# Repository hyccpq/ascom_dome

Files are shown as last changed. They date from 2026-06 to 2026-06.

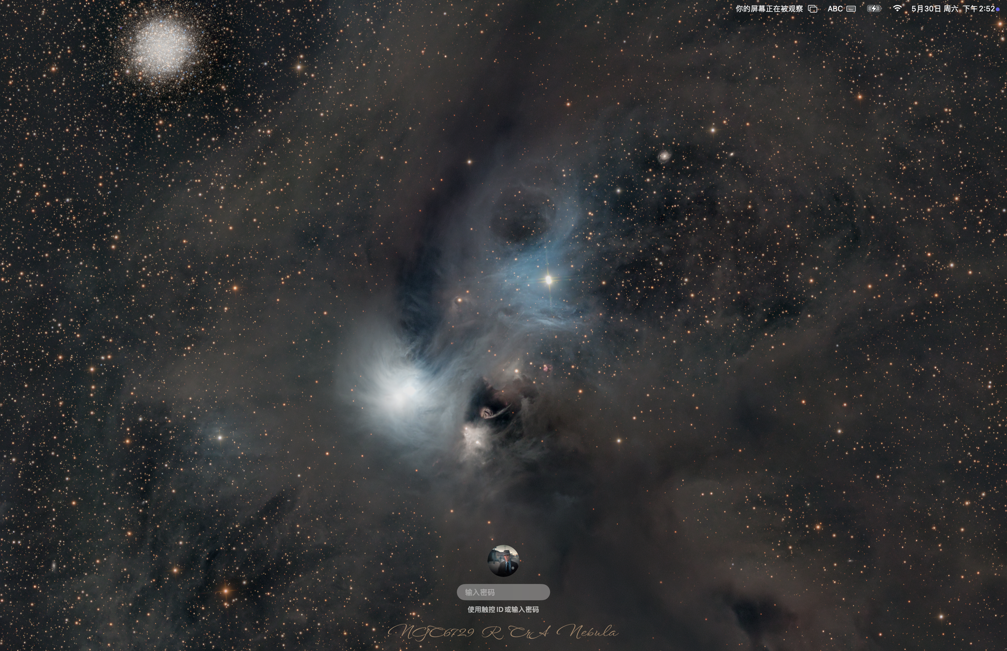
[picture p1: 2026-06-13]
hardware/jlceda/out/pcb3_outer_io_layout_screen.png

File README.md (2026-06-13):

# Ascom Alpaca ESP32 Dome Board

ESP32-S3 firmware for controlling a roll-off-roof / sliding dome top through the ASCOM Alpaca protocol.

This trimmed version keeps only the Dome control path:

- Alpaca Dome discovery and API endpoints
- Web page for Dome state and Open / Close / Halt commands
- Web setup for Dome pins and timeout settings
- WiFi manager connection flow
- OTA firmware and filesystem updates

Switch and CoverCalibrator modules have been removed from the firmware, web UI, SPIFFS defaults, and Alpaca device discovery.

## ESP32-S3 Dome I/O

The current firmware uses fixed GPIO definitions in `src/board_pins.h`:

| Signal | GPIO |
| --- | --- |
| Open command relay trigger | 4 |
| Close command relay trigger | 5 |
| Stop / halt command relay trigger | 6 |
| Open limit input | 7 |
| Close limit input | 8 |
| Reserved rain sensor input | 9 |

The three relay outputs are intended to pulse external isolated trigger inputs for open, close, and stop. The rain sensor header is initialized as an input and reported in diagnostics, but it does not automatically close the dome until the sensor polarity and desired safety behavior are defined.

The web setup page still stores the original dome configuration file for compatibility, but the active control pins are the fixed GPIO constants above.

Detailed hardware notes are in `docs/esp32-s3-dome-board-hardware.md`.

ESP32-S3 dome board wiring draft

## Build

Install Visual Studio Code and the PlatformIO extension, then open this folder as a PlatformIO project.

From the command line:

```sh
pio run
```

To build the SPIFFS image:

```sh
pio run --target buildfs
```

## First Upload

Use PlatformIO:

1. Upload Filesystem Image
2. Upload firmware

On first boot, connect to the WiFi manager access point and configure the board for your observatory WiFi.

## Web Interface

After the board joins WiFi, open the ESP32 IP address in a browser.

- `/` shows Dome status and Open / Close / Halt controls.
- `/setup` shows Dome configuration.
- `/update` is provided by ElegantOTA for firmware and filesystem updates.

## ASCOM Alpaca

The board listens for Alpaca discovery on UDP `32227` and serves Alpaca device requests on port `4567`.

Only one configured device is advertised:

- Device type: `Dome`
- Device number: `0`

Useful endpoints include:

- `GET /management/apiversions`
- `GET /management/v1/description`
- `GET /management/v1/configureddevices`
- `GET /api/v1/dome/0/shutterstatus`
- `PUT /api/v1/dome/0/openshutter`
- `PUT /api/v1/dome/0/closeshutter`
- `PUT /api/v1/dome/0/abortslew`

## Verification

Current smoke check:

```sh
pio run
```

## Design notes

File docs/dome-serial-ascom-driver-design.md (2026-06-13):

# Dome Serial Control and ASCOM Driver Design

This document defines the next development slice for the ESP32 dome controller:

1. Add a local serial control protocol to the firmware.
2. Build a Windows ASCOM Dome driver for ASCOM Platform 6.6 and later.
3. Keep the current Alpaca and browser controls working through the same internal dome command/state model.

## Current Firmware Baseline

The firmware is now dome-only.

Relevant files:

- `src/main.cpp` starts WiFi, Alpaca discovery, Dome routes, browser routes, OTA, and `main_loop()`.
- `src/Dome/dome.h` owns dome GPIO setup, command pulses, input state detection, and the movement state machine.
- `src/Dome/domeVariable.h` defines `Dome`, `ShCmdEnum`, `ShStEnum`, and `ShInEnum`.
- `src/Dome/alpacaDevices.h` exposes Alpaca Dome API methods.
- `src/Dome/webserver.h` exposes browser-facing `/api/dome` and `/api/dome-cmd`.

The serial protocol should not duplicate dome movement logic. It should only translate serial commands into the existing `Dome.ShutterCommand` and report the existing `Dome.ShutterState`.

## Official ASCOM References

Use these official references during implementation:

- ASCOM Platform 6.6 SP2 developer help: `https://ascom-standards.org/Help/Developer/html/N_ASCOM_DriverAccess.htm`
- ASCOM Platform requirements: `https://ascom-standards.org/Help/Developer/html/6cd2ca86-9e45-4a9e-8693-32d338c949a3.htm`
- ASCOM Dome DriverAccess class for Platform 6.6: `https://ascom-standards.org/Help/Developer/html/T_ASCOM_DriverAccess_Dome.htm`
- ASCOM Master Interfaces Dome API reference: `https://ascom-standards.org/library/html/T_ASCOM_DeviceInterface_IDomeV3.htm`
- ASCOM Alpaca API reference: `https://ascom-standards.org/api/`

Interpretation for this project:

- ASCOM Platform 6.6 targets .NET Framework 4.8.
- The 6.6 DriverAccess Dome class documents `IDomeV2` compatibility.
- Newer ASCOM interface documentation includes `IDomeV3`.
- For broad client compatibility, implement the first Windows driver as an ASCOM 6.6-compatible Dome driver, with a small internal adapter layer so an `IDomeV3` facade can be added later without rewriting serial transport.

## Serial Protocol Goals

The serial protocol is for a direct USB connection between Windows and the ESP32.

Goals:

- Human-readable for field debugging in a serial terminal.
- Line-oriented and non-blocking on the ESP32.
- Stable enough for an ASCOM driver.
- Idempotent status reads.
- Simple command acknowledgements.
- No JSON parsing required in the hot loop.

Transport defaults:

- Baud: `115200`
- Data bits: `8`
- Parity: `None`
- Stop bits: `1`
- Line ending: `\n`; accept optional preceding `\r`
- Encoding: ASCII
- Read timeout on driver side: 1000 ms
- Command timeout on driver side: 3000 ms

## Serial Protocol Version

Protocol name: `KDB1`

Every command is one line:

```text
KDB1 <COMMAND> [ARGS...]
```

Every response is one line:

```text
OK <FIELDS...>
ERR <CODE> <MESSAGE>
```

The driver must ignore blank lines. The firmware should trim whitespace and treat command names case-insensitively.

## Serial Commands

### `PING`

Request:

```text
KDB1 PING
```

Response:

```text
OK PONG KDB1
```

Driver use:

- Verify selected COM port.
- Reconnect health check.

### `INFO`

Request:

```text
KDB1 INFO
```

Response:

```text
OK NAME=KalecDome PROTO=KDB1 FW=1.0 DEVICE=DOME
```

Driver use:

- Confirm this is the expected device.
- Display firmware/protocol in setup dialog.

### `STATE`

Request:

```text
KDB1 STATE
```

Response:

```text
OK STATE=OPEN CMD=IDLE INPUT=OPEN MOVING=0 ERROR=0
```

Allowed `STATE` values:

- `OPEN`
- `CLOSED`
- `OPENING`
- `CLOSING`
- `ERROR`

Allowed `CMD` values:

- `IDLE`
- `OPEN`
- `CLOSE`
- `HALT`

Allowed `INPUT` values:

- `NONE`
- `CLOSE`
- `OPEN`
- `BOTH`

Driver mapping:

| Firmware state | ASCOM shutter status |
| --- | --- |
| `OPEN` | `shutterOpen` |
| `CLOSED` | `shutterClosed` |
| `OPENING` | `shutterOpening` |
| `CLOSING` | `shutterClosing` |
| `ERROR` | `shutterError` |

### `OPEN`

Request:

```text
KDB1 OPEN
```

Success response:

```text
OK CMD=OPEN
```

Error responses:

```text
ERR 1035 ALREADY_OPEN_OR_MOVING
ERR 1001 DEVICE_ERROR
```

Firmware behavior:

- If state is already `OPEN`, return `ERR 1035 ALREADY_OPEN_OR_MOVING`.
- If no movement is active, set `Dome.ShutterCommand = CmdOpen`.
- Do not block waiting for the movement to finish.

### `CLOSE`

Request:

```text
KDB1 CLOSE
```

Success response:

```text
OK CMD=CLOSE
```

Error responses:

```text
ERR 1035 ALREADY_CLOSED_OR_MOVING
ERR 1001 DEVICE_ERROR
```

Firmware behavior:

- If state is already `CLOSED`, return `ERR 1035 ALREADY_CLOSED_OR_MOVING`.
- If no movement is active, set `Dome.ShutterCommand = CmdClose`.
- Do not block waiting for the movement to finish.

### `HALT`

Request:

```text
KDB1 HALT
```

Response:

```text
OK CMD=HALT
```

Firmware behavior:

- Set `Dome.ShutterCommand = CmdHalt`.
- Set `Dome.Cycle = 100` to enter the existing halt cycle.

### `CONFIG?`

Request:

```text
KDB1 CONFIG?
```

Response:

```text
OK OPEN_RELAY=4 CLOSE_RELAY=5 HALT_RELAY=6 OPEN_INPUT=7 CLOSE_INPUT=8 RAIN_INPUT=9 TIMEOUT=300
```

Driver use:

- Show read-only hardware summary in the setup dialog.

## Firmware Implementation Plan

Add a new firmware module:

- `src/Dome/serialControl.h`

Current status: implemented.

Expose:

```cpp
void domeSerialSetup();
void domeSerialLoop();
```

Call sites:

- In `setup()`, call `domeSerialSetup()` after `initDomeConfig()`.
- In `main_loop()`, call `domeSerialLoop()` after `domehandlerloop()`.

Implementation notes:

- Reuse the existing `Serial.begin(115200)` from `setup()`.
- Maintain a small input buffer, for example 96 bytes.
- Read from `Serial.available()` without blocking.
- Process a command only after `\n`.
- Reject overlong lines with `ERR 1002 LINE_TOO_LONG`.
- Keep all response generation in one small helper.
- Avoid `delay()` in serial parsing; dome movement code already contains command pulse delays.

Suggested errors:

| Code | Meaning |
| --- | --- |
| `1000` | Unknown command |
| `1001` | Device error |
| `1002` | Line too long |
| `1003` | Bad protocol prefix |
| `1035` | Invalid operation for current state |

Implemented command examples:

```text
> KDB1 PING
< OK PONG KDB1

> KDB1 INFO
< OK NAME=KalecDome PROTO=KDB1 FW=1.0 DEVICE=DOME

> KDB1 STATE
< OK STATE=CLOSED CMD=IDLE INPUT=CLOSE MOVING=0 ERROR=0

> KDB1 OPEN
< OK CMD=OPEN

> KDB1 CLOSE
< OK CMD=CLOSE

> KDB1 HALT
< OK CMD=HALT

> KDB1 CONFIG?
< OK OPEN_RELAY=4 CLOSE_RELAY=5 HALT_RELAY=6 OPEN_INPUT=7 CLOSE_INPUT=8 RAIN_INPUT=9 TIMEOUT=300
```

## ASCOM Driver Architecture

Project type:

- Windows ASCOM Dome driver.
- C#.
- .NET Framework 4.8.
- Built with ASCOM Platform 6.6 developer components.
- COM-registered local driver using ASCOM driver templates where possible.

Driver identity:

- ProgID: `ASCOM.KalecDome.Dome`
- Display name: `Kalec Dome Serial`
- Device type: `Dome`

Internal layers:

| Layer | Responsibility |
| --- | --- |
| `DomeDriver` | ASCOM interface implementation and COM registration surface |
| `DomeController` | Maps ASCOM methods/properties to transport commands |
| `SerialTransport` | Owns `System.IO.Ports.SerialPort`, timeouts, reconnect, command lock |
| `ProtocolParser` | Parses `OK` / `ERR` response lines and typed fields |
| `ProfileSettings` | Stores COM port, baud, trace option, command timeout |
| `SetupDialog` | Lets user select/test COM port |

Threading:

- Serialize all COM port access with a single lock.
- Never allow concurrent serial commands.
- Keep ASCOM properties fast by using `STATE` polling with a short timeout.
- Throw ASCOM exceptions on serial timeout or protocol error.

## ASCOM Dome Method Mapping

| ASCOM member | Driver behavior |
| --- | --- |
| `Connected get` | Return internal connection state |
| `Connected set true` | Open COM port, send `PING`, send `INFO` |
| `Connected set false` | Close COM port |
| `Name` | `Kalec Dome Serial` |
| `Description` | `Serial ASCOM driver for Kalec ESP32 dome controller` |
| `DriverInfo` | Include driver version and protocol version |
| `DriverVersion` | Semantic version, start with `0.1.0` |
| `InterfaceVersion` | `2` for ASCOM Platform 6.6 compatibility |
| `ShutterStatus` | Send `STATE`, map firmware state to ASCOM enum |
| `OpenShutter()` | Send `OPEN` |
| `CloseShutter()` | Send `CLOSE` |
| `AbortSlew()` | Send `HALT` |
| `CanSetShutter` | `true` |
| `Slewing` | `true` for `OPENING` or `CLOSING` |
| `CanFindHome` | `false` |
| `CanPark` | `false` |
| `CanSetAltitude` | `false` |
| `CanSetAzimuth` | `false` |
| `CanSetPark` | `false` |
| `CanSlave` | `false` |
| `CanSyncAzimuth` | `false` |
| Unsupported movement/position methods | Throw ASCOM `MethodNotImplementedException` |
| Unsupported position properties | Throw ASCOM `PropertyNotImplementedException` |

For a later `IDomeV3` facade, keep connection operations inside `DomeController` so async connect/disconnect semantics can wrap the same serial connect/test sequence.

## Driver Setup Dialog

Fields:

- COM port dropdown.
- Baud rate, default `115200`; advanced setting.
- Test connection button.
- Trace logging checkbox.
- Timeout setting, default `3000 ms`.

Test flow:

1. Open selected port.
2. Send `KDB1 PING`.
3. Send `KDB1 INFO`.
4. Show device name, firmware version, and protocol.
5. Save settings only after successful test, unless the user explicitly overrides in the dialog.

## Validation and Test Plan

Firmware:

- `pio run`
- `pio run --target buildfs`
- Serial terminal manual tests:
  - `KDB1 PING`
  - `KDB1 INFO`
  - `KDB1 STATE`
  - `KDB1 OPEN`
  - `KDB1 CLOSE`
  - `KDB1 HALT`

Driver:

- Unit test protocol parser with representative `OK` and `ERR` lines.
- Unit test ASCOM state mapping.
- Manual setup dialog test against ESP32.
- ASCOM Diagnostics device selection.
- ASCOM Conform test for Dome behavior.
- N.I.N.A. connection smoke test.

Hardware safety checks:

- Verify OPEN command pulses only GPIO 4.
- Verify CLOSE command pulses only GPIO 5.
- Verify HALT pulls GPIO 6 high and clears open/close relays.
- Verify state reads map GPIO 7/8 to open/closed/error consistently.
- Verify repeated `OPEN` while moving does not re-trigger a relay pulse.

## Implementation Milestones

1. Firmware serial protocol skeleton:
   - Add `serialControl.h`.
   - Support `PING`, `INFO`, `STATE`.
   - Verify with serial monitor.

2. Firmware command execution:
   - Add `OPEN`, `CLOSE`, `HALT`, `CONFIG?`.
   - Verify relay behavior and no blocking parser issues.

3. Driver scaffold:
   - Create ASCOM Dome driver project.
   - Add profile settings and setup dialog.
   - Implement `SerialTransport`.

4. Driver command mapping:
   - Implement connection, status, open, close, halt.
   - Add parser and mapping tests.

5. Compatibility testing:
   - ASCOM Diagnostics.
   - ASCOM Conform.
   - N.I.N.A. or other ASCOM 6.6+ client.

## Open Design Decisions

- Whether to keep the driver serial-only or add optional Alpaca-over-WiFi fallback later.
- Whether firmware pin configuration should remain stored in `domeconfig.txt` or be fully replaced by fixed GPIO constants.
- Whether the ASCOM driver should expose a polling interval setting or always poll on demand.
- Whether the driver installer should be WiX/MSI or a simpler developer registration script for early testing.

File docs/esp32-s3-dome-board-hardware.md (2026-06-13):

# ESP32-S3 平移顶控制板硬件设计建议

本文档记录当前控制板的建议硬件方案。目标是用 ESP32-S3 控制天文台平移顶，通过 ASCOM Alpaca / Web / 串口命令触发开顶、关顶、停止，并为雨感、急停和 RS485 扩展预留接口。

## 设计结论

第一版建议采用：

- 三路继电器干接点作为主控制输出：开、关、停。
- 两路限位输入作为核心状态反馈：开到位、关到位。
- 一路雨感输入预留，先只做状态采集，不直接自动关顶。
- 一路急停输入预留，优先级高于所有软件命令。
- RS485 作为扩展接口预留，不作为第一版主控制依赖。

这样做的好处是兼容性高、调试简单、现场故障容易定位，同时保留后续接 Modbus RTU、PLC 或智能电机控制器的空间。

## 接线框图

下面是第一版建议的直观接线结构。ESP32-S3 控制板负责网络、状态机和继电器触发；外部电机控制器仍然负责真正的大功率电机动作。

```mermaid
flowchart LR
    subgraph Board["ESP32-S3 平移顶控制板"]
        ESP["ESP32-S3\nAlpaca / Web / Serial"]
        RelayOpen["开继电器\nGPIO 4"]
        RelayClose["关继电器\nGPIO 5"]
        RelayStop["停继电器\nGPIO 6"]
        Inputs["输入保护 / 滤波\nGPIO 7 / 8 / 9"]
        RS485["RS485 预留\nUART + DE/RE"]
        Power["电源转换\nVIN -> 5V -> 3V3"]
    end

    subgraph OutputTB["继电器输出接线柱"]
        OpenTB["OPEN_COM / OPEN_NO"]
        CloseTB["CLOSE_COM / CLOSE_NO"]
        StopTB["STOP_COM / STOP_NO"]
    end

    subgraph MotorCtrl["外部电机/门机控制器"]
        OpenIn["开按钮输入"]
        CloseIn["关按钮输入"]
        StopIn["停按钮输入"]
        Motor["平移顶电机"]
    end

    subgraph SensorTB["状态输入接线柱"]
        OpenLimit["开到位限位"]
        CloseLimit["关到位限位"]
        Rain["雨感传感器"]
        Estop["急停输入"]
    end

    subgraph LocalTB["本地按钮接线柱"]
        ManualOpen["本地开"]
        ManualClose["本地关"]
        ManualStop["本地停"]
    end

    subgraph CommTB["通信/电源接线柱"]
        AB["RS485 A / B / GND"]
        Vin["VIN+ / VIN- / PE"]
    end

    ESP --> RelayOpen --> OpenTB --> OpenIn
    ESP --> RelayClose --> CloseTB --> CloseIn
    ESP --> RelayStop --> StopTB --> StopIn
    OpenIn --> Motor
    CloseIn --> Motor
    StopIn --> Motor

    OpenLimit --> Inputs --> ESP
    CloseLimit --> Inputs
    Rain --> Inputs
    Estop --> Inputs
    ManualOpen --> Inputs
    ManualClose --> Inputs
    ManualStop --> Inputs

    ESP <--> RS485 <--> AB
    Vin --> Power --> ESP
```

核心理解：

- 左边继电器输出只是模拟按钮，不直接驱动电机。
- 下方限位、雨感、急停、本地按钮都走低压输入端子。
- RS485 只是预留扩展，不影响第一版三继电器控制。
- 电源输入、继电器触点、低压输入尽量分区放置。

## 固件引脚定义

当前固件固定使用 `src/board_pins.h` 中的板级引脚定义：

| 功能 | GPIO | 方向 | 说明 |
| --- | --- | --- | --- |
| Open relay trigger | GPIO 4 | 输出 | 开顶继电器触发 |
| Close relay trigger | GPIO 5 | 输出 | 关顶继电器触发 |
| Halt relay trigger | GPIO 6 | 输出 | 停止继电器触发 |
| Open limit | GPIO 7 | 输入 | 开到位限位 |
| Close limit | GPIO 8 | 输入 | 关到位限位 |
| Rain sensor | GPIO 9 | 输入 | 雨感预留输入 |

继电器输出在上电初始化时会被拉低，避免启动瞬间误触发。

## 控制输出

### 推荐形式

三路输出建议使用继电器干接点：

- `OPEN_RELAY`: 模拟外部控制器的“开”按钮。
- `CLOSE_RELAY`: 模拟外部控制器的“关”按钮。
- `STOP_RELAY`: 模拟外部控制器的“停”按钮。

干接点不要把本板 GND 或电源直接带到外部电机控制器。这样可以兼容更多门机、卷帘门控制板、PLC 输入和自制控制箱。

### 继电器驱动建议

每路继电器建议包含：

- ESP32-S3 GPIO 驱动三极管或 MOSFET。
- 线圈反灌保护二极管。
- 继电器动作 LED。
- 触点侧使用接线端子引出 `COM` / `NO`，必要时可增加 `NC`。
- 继电器线圈供电与 MCU 电源做好去耦。

如果空间允许，可以选用光耦继电器或信号继电器。普通机械继电器最直观，现场维护也方便。

### 触发时间

当前固件的开/关/停继电器脉冲约为 1 秒。后续可以把脉冲时间做成配置项：

| 输出 | 建议可配置范围 |
| --- | --- |
| 开继电器 | 200 ms - 2000 ms |
| 关继电器 | 200 ms - 2000 ms |
| 停继电器 | 200 ms - 2000 ms |

有些控制器只需要短按，有些控制器需要稍长按压，保留可配置会更稳。

## 状态输入

### 限位输入

至少需要两路限位输入：

- `OPEN_LIMIT`: 屋顶完全打开。
- `CLOSE_LIMIT`: 屋顶完全关闭。

建议输入侧做以下保护：

- 明确上拉或下拉，不让输入悬空。
- 串联限流电阻。
- RC 滤波，减少长线干扰。
- TVS 或 ESD 保护。
- 必要时使用光耦隔离。

平移顶电机附近干扰较多，限位线又可能比较长，输入保护比“能读到电平”更重要。

### 状态判定

固件当前按两路限位组合判断状态：

| 开限位 | 关限位 | 状态 |
| --- | --- | --- |
| 有效 | 无效 | 已打开 |
| 无效 | 有效 | 已关闭 |
| 有效 | 有效 | 运动中或停止在中间 |
| 无效 | 无效 | 异常状态 |

实际硬件接线时要确认限位开关是常开还是常闭，并让固件读取到的电平符合这个状态表。后续如果改用常闭安全回路，建议同步调整固件状态表和文档。

## 雨感接口

建议预留一路雨感输入端子：

- `RAIN_SENSOR`
- `GND`
- `3V3` 或 `5V`，按传感器模块选择

雨感模块常见输出有两类：

- 数字量输出：干湿阈值由模块电位器决定。
- 模拟量输出：湿度程度由 ADC 读取。

第一版建议先接数字量输入，因为逻辑简单、可靠性高。固件目前只初始化雨感输入并在诊断中报告引脚，不自动关顶。等确认传感器输出极性后，再决定：

- 雨感触发时禁止开顶。
- 雨感触发且屋顶未关闭时自动关顶。
- 雨感触发后需要人工确认才能重新开顶。

雨感属于安全相关输入，不建议第一版在没有现场验证的情况下直接自动动作。

## 急停和安全联锁

建议预留急停输入，优先级高于 Web、Alpaca、串口和自动逻辑。

推荐策略：

- 急停触发时立即断开开/关继电器输出。
- 急停触发时允许或强制触发停继电器，取决于外部控制器逻辑。
- 急停解除后不自动恢复动作，需要新的人工命令。

更保守的硬件方案是增加继电器输出总使能，使急停能在硬件层面切断所有运动命令。软件停机很好，但硬件急停更可靠。

## RS485 预留

RS485 不建议作为第一版主控制输出，但强烈建议预留。

### 适合 RS485 的场景

- 外部电机控制器支持 Modbus RTU。
- 后续要接 PLC。
- 需要读取更多状态，例如电机故障码、电流、速度、门机状态。
- 设备距离较长，现场干扰较重。

### 不适合作为第一版主控制的原因

- 必须知道并维护对方协议。
- 不同控制器协议差异大。
- 调试复杂度高于开关量。
- 更换电机控制器时固件可能也要改。

### 硬件预留建议

预留一组 UART 给 RS485 收发器，例如 MAX3485 / SP3485：

| 信号 | 说明 |
| --- | --- |
| TXD | ESP32-S3 UART TX |
| RXD | ESP32-S3 UART RX |
| DE/RE | 方向控制 GPIO |
| A | RS485 A |
| B | RS485 B |
| GND | 通信参考地 |

板上建议增加：

- 120R 终端电阻，使用跳帽或拨码开关启用。
- 偏置电阻位置，按总线实际情况决定是否焊接。

## PCB 布局约束

当前 JLCEDA 生产候选页面为 `ascom_dome` / `Board3_1` / `PCB3`，按低成本 2 层板方向整理：

- 板框约为 `3600 mil x 3450 mil`，控制在常见低价打样尺寸内。
- 四角预留 M3 安装孔，孔径约 `3.4 mm`，非金属化孔。
- 上边放限位/雨感/RS485 预留端子，底边放 `5V IN` 和 USB-C，右边放三路继电器干接点端子，方便现场压线。
- 三路继电器触点输出使用较粗走线，低压 GPIO/传感器信号使用细线。
- RS485 收发器、120R 终端电阻作为预留/可不焊方案，第一版不依赖 RS485。
- ESP32-S3-WROOM 天线区域在文档层标出；正式下单前必须以 live `PCB3` 重新确认无铜、无走线、无过孔、无器件。

当前 JLCEDA 外设布局预览见 [pcb3_outer_io_current_simplified.svg.png](/Users/kalec/Desktop/Ascom-Alpacha-ESP32-Switch-Borad-Dome-Board/hardware/jlceda/out/pcb3_outer_io_current_simplified.svg.png)。

JLCEDA `PCB3` 是当前目标生产候选。此前 live `PCB3` 已完成嘉立创/LCSC 器件、M3 孔位避让、开路检查和铜间距检查；但当前 `R1/R2` 边距修正仍停留在脚本侧，JLCEDA 客户端/bridge 断开后还没有写入并读回确认。正式下单前仍需重新连接、应用当前脚本、同步原理图网表并重新跑 UI DRC。JLCEDA 客户端不可用时，仓库里还保留一份本地 KiCad 机械/布局基线，便于继续检查板框、M3 孔位、端子位置和成本策略：

- KiCad PCB: [esp32_s3_dome_controller.kicad_pcb](/Users/kalec/Desktop/Ascom-Alpacha-ESP32-Switch-Borad-Dome-Board/hardware/kicad/esp32_s3_dome_controller.kicad_pcb)
- 当前交付索引: [esp32-s3-dome-board-delivery.md](/Users/kalec/Desktop/Ascom-Alpacha-ESP32-Switch-Borad-Dome-Board/docs/esp32-s3-dome-board-delivery.md)
- KiCad 预览图: [kicad-esp32-s3-dome-controller-preview.svg](/Users/kalec/Desktop/Ascom-Alpacha-ESP32-Switch-Borad-Dome-Board/docs/kicad-esp32-s3-dome-controller-preview.svg)
- KiCad DRC 报告: [drc.rpt](/Users/kalec/Desktop/Ascom-Alpacha-ESP32-Switch-Borad-Dome-Board/hardware/kicad/out/drc.rpt)
- KiCad Gerber/Drill 草包: [fab](/Users/kalec/Desktop/Ascom-Alpacha-ESP32-Switch-Borad-Dome-Board/hardware/kicad/out/fab)
- KiCad Gerber/Drill 草包 ZIP: [esp32_s3_dome_controller_fab_preview.zip](/Users/kalec/Desktop/Ascom-Alpacha-ESP32-Switch-Borad-Dome-Board/hardware/kicad/out/esp32_s3_dome_controller_fab_preview.zip)
- V1 BOM 成本草表: [esp32-s3-dome-board-bom.csv](/Users/kalec/Desktop/Ascom-Alpacha-ESP32-Switch-Borad-Dome-Board/docs/esp32-s3-dome-board-bom.csv)
- 标准化器件分配表: [esp32-s3-dome-board-standard-parts.md](/Users/kalec/Desktop/Ascom-Alpacha-ESP32-Switch-Borad-Dome-Board/docs/esp32-s3-dome-board-standard-parts.md)
- 标准化器件 CSV: [esp32-s3-dome-board-standard-parts.csv](/Users/kalec/Desktop/Ascom-Alpacha-ESP32-Switch-Borad-Dome-Board/docs/esp32-s3-dome-board-standard-parts.csv)
- 嘉立创/LCSC 物料候选 BOM: [esp32-s3-dome-board-jlc-bom.csv](/Users/kalec/Desktop/Ascom-Alpacha-ESP32-Switch-Borad-Dome-Board/docs/esp32-s3-dome-board-jlc-bom.csv)
- 嘉立创/LCSC 物料核对记录: [esp32-s3-dome-board-jlc-source-check.md](/Users/kalec/Desktop/Ascom-Alpacha-ESP32-Switch-Borad-Dome-Board/docs/esp32-s3-dome-board-jlc-source-check.md)
- JLCEDA 收尾清单: [esp32-s3-dome-board-jlceda-finish-checklist.md](/Users/kalec/Desktop/Ascom-Alpacha-ESP32-Switch-Borad-Dome-Board/docs/esp32-s3-dome-board-jlceda-finish-checklist.md)
- 封装替换映射表: [esp32-s3-dome-board-footprint-map.csv](/Users/kalec/Desktop/Ascom-Alpacha-ESP32-Switch-Borad-Dome-Board/docs/esp32-s3-dome-board-footprint-map.csv)
- 投板/装配注意事项: [esp32-s3-dome-board-fab-notes.md](/Users/kalec/Desktop/Ascom-Alpacha-ESP32-Switch-Borad-Dome-Board/docs/esp32-s3-dome-board-fab-notes.md)
- 坐标文件: [esp32_s3_dome_controller_pos.csv](/Users/kalec/Desktop/Ascom-Alpacha-ESP32-Switch-Borad-Dome-Board/hardware/kicad/out/esp32_s3_dome_controller_pos.csv)

这份 KiCad 文件是离线备份基线，不替代 JLCEDA `PCB3` 正式投板文件。此前 JLCEDA `PCB3` 已记录以下候选状态，bridge 恢复后必须用当前脚本重新复验：

- 使用嘉立创/LCSC 器件源；此前 `scripts/jlceda_verify_lcsc_parts.mjs` 确认 30 个器件的 `supplierId` 均匹配预期。
- 标准化器件已经固定在 `docs/esp32-s3-dome-board-standard-parts.md` 和 `.csv`，用于约束 FIT/DNP、替代料和下单前检查。
- `J5/R8/U2` 作为 RS485 预留默认不进 BOM，其余 V1 必需器件进 BOM。
- USB-C 已靠底边并朝外，`J1 5V IN` 同在底边；J2/J3/J4 继电器输出端子靠右边。
- J6/J7/J8/J5 位于上边，分别用于开限位、关限位、雨感和 RS485 预留。
- 非母线类信号走线已改为 45 度倒角；`5V/GND/3V3/RS485` 这类公共母线保持直连，避免倒角切断分支汇合点。
- `J1/J6/J7/J8` 已从四角 M3 孔附近让开；此前 `scripts/jlceda_verify_mounting_clearance.mjs` 检查四个孔周围器件、走线、过孔命中均为 `0`。
- 此前 `scripts/jlceda_find_open_nets_layered.mjs` 检查 `openNetCount: 0`。
- 此前 `scripts/jlceda_check_clearance.mjs` 检查线/焊盘、线/线、线/过孔、过孔/过孔冲突均为 `0`。
- 此前 JLCEDA `pcb_Drc.check(true, false, true)` 检查无 clearance、slot、connection 等物理布线错误；`P2.Schematic3` 已按 `PCB3` 修正继电器 pinout、RS485 A/B、USB/EN 和外壳 GND，直接 Ref.Pin 比对显示 `103` 个 P2 有网引脚与 `103` 个 PCB3 有网焊盘完全一致。当前只剩 1 条 JLCEDA UI generic `Netlist Error / Import Changes` 同步项；正式下单前需要先应用当前 `R1/R2` 脚本修正，再清掉该 UI 项并重新跑 DRC。

当前 KiCad 备份布局已完成以下内容：

- 板框约 `91.44 mm x 87.63 mm`，控制在 `100 mm x 100 mm` 以内。
- 四角 M3 非金属化安装孔已预留。
- 电源输入、限位/雨感输入、RS485 预留和三路继电器干接点端子均靠板边布置。
- ESP32-S3-WROOM 天线禁布区已在 PCB `Dwgs.User` 层标注；正式换官方封装时，天线端必须朝板边，禁布区内不能有铜皮、走线、过孔或器件。
- 三路继电器触点侧已使用较粗走线，输入侧和控制侧使用细走线。
- 已补入输入端子、雨感、GND、5V、3V3、三路继电器驱动、RS485 A/B 和 USB-C 调试口的布线。
- 已新增 `J9 USB-C DEVICE`，作为 ESP32-S3 原生 USB 下载/调试口；`VBUS` 接 5V，`D-`/`D+` 接 ESP32-S3 USB 引脚，`CC1`/`CC2` 各接 5.1k 下拉。
- `J1 5V IN` 已保留为外部 5V 接线柱输入，并在板上补充 `GND +5V IN` 丝印，避免现场接线只看编号。
- DRC 未发现短路、交叉、clearance、hole-clearance 或 solder-mask-bridge 硬错误。
- DRC 当前未连接项为 `0`，严格错误检查为 `0`。
- KiCad 备份完整 DRC 仍有 `34` 条 `lib_footprint_mismatch` 警告，来源是生成的 `Codex:*` 占位封装；若单独用 KiCad 备份投板，必须先替换成嘉立创/立创 EDA 可采购封装。此前 JLCEDA `PCB3` 已用真实 LCSC 封装完成候选构建，但当前仍需 bridge 恢复后复验。

### 成本优化建议

- 第一版保持 2 层板，不做 4 层板。
- 板子尺寸继续压在 `100 mm x 100 mm` 内。
- RS485 相关器件可标注为 DNP，现场确认需要后再焊；其中 `R8 120R` 终端电阻建议第一版默认 DNP。
- 端子尽量统一间距和型号，减少 BOM 种类。
- 继电器只引出 `COM/NO`，如果现场确认不需要 `NC`，不额外增加三位端子。
- M3 孔使用普通非金属化安装孔，不做沉金、半孔等特殊工艺。
- 贴装电阻优先用嘉立创 Basic 0603：`100R C22775`、`10k C25804`、`120R C22787`、`5.1k C23186`。

### KiCad 备份 PCB 状态

已完成：

- 板框恢复到 PCB 内部的 Board Outline 层。
- 四角 M3 安装孔已放入 PCB。
- 三路继电器干接点输出已布到底层端子：`OPEN_COM/NO`、`CLOSE_COM/NO`、`STOP_COM/NO`。
- 继电器线圈低端到 MOSFET/续流二极管的本地连接已整理。
- 5V 和 3V3 已完成一部分电源主干。
- R4/R5/R6 已移到 ESP32-S3 附近并旋转，使输入信号焊盘朝向 MCU，降低端子区拥挤度。
- `OPEN_LIMIT_GPIO7`、`CLOSE_LIMIT_GPIO8`、`RAIN_GPIO9` 已从端子经底层走线接到 ESP32-S3 输入和上拉电阻。
- R1/R2/R3 已重新摆放到 MOSFET gate 附近，三路 `OPEN_GATE`、`CLOSE_GATE`、`STOP_GATE` 已接到 MOSFET 门极。
- `OPEN_GPIO4`、`CLOSE_GPIO5`、`STOP_GPIO6` 已从 ESP32-S3 接到 R1/R2/R3，三路继电器控制信号已收线。
- R1 已下移并同步调整 `OPEN_GPIO4` 末端走线，为 `OPEN_COIL_LOW` 继续优化预留间距。
- 三路继电器 5V 线圈供电主干已串接，D2 5V 支路已补齐。
- `J9 USB-C DEVICE` 已放在板边，采用低成本原生 USB 方案，不增加 USB-UART 芯片。
- U3 到 C1 的 3V3 去耦支路已绕开 U3 中间脚完成。
- RS485 的 `RE` / `DE` 已在 U2 旁短接，便于后续用一个 GPIO 控制方向。
- RS485 A/B 已从 U2 收发器接到 J5 端子；R8 终端电阻仍建议按 DNP/跳帽方案保留。
- U3 稳压器 GND 和 Q1 继电器驱动源极已补过孔接入底层 GND 回路。

KiCad 备份基线如果继续单独投板，还需要：

- RS485 RO/DI 与 MCU UART 的预留走线仍建议在原理图层面确认；当前 PCB 侧 A/B 端子和 R8 DNP 位已保留。
- 如果为了进一步降 BOM 成本决定删除 `R8 120R`，必须原理图和 PCB 同步删除或同步改为 DNP；不要只在 PCB 端删除，否则会产生 netlist mismatch。
- GND 建议最终用覆铜处理，并在 ESP32-S3 模块 GND、Q2/Q3 源极、U3、J6/J7/J5/J9 GND 处补回流过孔；如果 API 覆铜不可用，就保持当前分区地线加过孔的策略。
- USB-C 最终投板前应换成实际采购的 Type-C 母座封装，并按所选连接器核对外壳脚、定位孔和板边开口。
- ESP32-S3 模组最终投板前必须用官方 footprint 复核天线 keepout；如果真实封装和当前占位 U1 不一致，优先调整 U1 位置/方向，让天线禁布区伸向板边空旷区域。

当前 KiCad 离线版 DRC 没有短路、交叉、clearance、hole-clearance、solder-mask-bridge 或未连接错误。丝印重叠/压铜警告已清理；剩余主要是自定义占位 footprint 与库副本不一致的警告，因此这版可作为继续导入/复刻到 JLCEDA 的电气布局基线，但正式投板前仍要替换为真实封装。
- TVS 管保护 A/B 线。
- 接线端子标清 A/B/GND。

## 电源和保护

建议供电结构：

- 外部输入：推荐 12 V 或 24 V，按现场供电选择。
- 板载降压到 5 V，给继电器和部分外设。
- 再降压到 3.3 V，给 ESP32-S3。

保护建议：

- 输入保险丝或自恢复保险。
- 电源反接保护。
- 输入 TVS。
- 继电器线圈独立去耦。
- ESP32-S3 3.3 V 电源留足瞬态余量。
- 外部长线接口增加 ESD/浪涌保护。

## 调试和维护

强烈建议板上放这些指示灯：

| 指示灯 | 作用 |
| --- | --- |
| POWER | 主电源正常 |
| 3V3 | MCU 电源正常 |
| WIFI/STATUS | 系统运行状态 |
| OPEN_RELAY | 开继电器动作 |
| CLOSE_RELAY | 关继电器动作 |
| HALT_RELAY | 停继电器动作 |
| OPEN_LIMIT | 开到位输入 |
| CLOSE_LIMIT | 关到位输入 |
| RAIN | 雨感输入 |
| ESTOP | 急停输入 |

另外建议预留：

- USB-C 或 USB-UART 下载调试口。
- BOOT / RESET 按键。
- UART TX/RX 测试点。
- 3V3 / 5V / GND 测试点。
- RS485 A/B 测试点。

现场调试时，输入输出 LED 会极大减少排查时间。

## 推荐端子规划

板子上尽量把外部连接都做成接线柱，方便现场接线、排查和后期替换设备。建议端子按功能分组，避免强弱电混在一起；每组端子旁边直接丝印功能名，不要只写 GPIO 编号。

推荐优先使用 3.5 mm 或 5.08 mm 间距插拔式接线端子。低压信号可以用 3.5 mm，继电器触点和外部控制线建议用 5.08 mm，现场拧线会舒服很多。

### 建议接线柱编号

第一版建议直接按下面编号画原理图和 PCB 丝印。编号不是强制，但这样后续对文档、原理图和接线说明时不容易乱。

| 编号 | 建议端子 | 间距 | 端子定义 | 备注 |
| --- | --- | --- | --- | --- |
| J1 | 电源输入 | 5.08 mm 3P | `VIN+`, `VIN-`, `PE/SHIELD` | 推荐 12 V 或 24 V 输入，按电源方案定 |
| J2 | 开继电器输出 | 5.08 mm 2P/3P | `OPEN_COM`, `OPEN_NO`, 可选 `OPEN_NC` | 干接点模拟开按钮 |
| J3 | 关继电器输出 | 5.08 mm 2P/3P | `CLOSE_COM`, `CLOSE_NO`, 可选 `CLOSE_NC` | 干接点模拟关按钮 |
| J4 | 停继电器输出 | 5.08 mm 2P/3P | `STOP_COM`, `STOP_NO`, 可选 `STOP_NC` | 干接点模拟停按钮 |
| J5 | 限位/安全输入 | 3.5 mm 6P | `OPEN_LIMIT`, `CLOSE_LIMIT`, `RAIN_SENSOR`, `EMERGENCY_STOP`, `GND`, `SENSOR_VCC` | `SENSOR_VCC` 建议跳帽选 3V3/5V |
| J6 | 本地按钮输入 | 3.5 mm 4P | `MANUAL_OPEN`, `MANUAL_CLOSE`, `MANUAL_STOP`, `GND` | 固件可后续接入 |
| J7 | RS485 | 3.5 mm 3P/4P | `A`, `B`, `GND`, 可选 `5V_OUT` | 预留 Modbus/PLC 扩展 |
| J8 | 下载/调试 | 2.54 mm 排针或 USB-C | `USB_D+`, `USB_D-`, `5V`, `GND` 或 UART | 结合 ESP32-S3 下载方式决定 |

当前 KiCad 离线版为了先压低成本和面积，端子编号略有简化：`J1` 是 2P `GND/+5V IN`，`J6/J7/J8` 分别是开限位、关限位和雨感输入，`J9` 是 USB-C 下载/调试口。正式同步到 JLCEDA 时，建议按最终原理图重新统一编号和丝印。

如果板子空间允许，继电器输出建议全部做 3P：`COM/NO/NC`。如果空间紧张，继电器输出至少做 2P：`COM/NO`。

### 继电器输出端子

三路继电器输出是最核心接口，建议每路独立接线柱：

```text
OPEN_COM
OPEN_NO
CLOSE_COM
CLOSE_NO
STOP_COM
STOP_NO
```

如空间允许，更推荐每路 `COM / NO / NC` 三端子，兼容常开和常闭外部回路：

```text
OPEN_COM
OPEN_NO
OPEN_NC
CLOSE_COM
CLOSE_NO
CLOSE_NC
STOP_COM
STOP_NO
STOP_NC
```

如果板子空间紧张，第一版至少保留 `COM / NO`。多数外部控制器模拟按钮只需要常开干接点。

### 状态输入端子

状态输入建议集中放一组接线柱，并给传感器供电预留公共端：

```text
OPEN_LIMIT
CLOSE_LIMIT
RAIN_SENSOR
EMERGENCY_STOP
GND
3V3/5V_SENSOR
```

如果使用三线传感器或不同电压雨感模块，可以把传感器电源单独做跳帽选择：

```text
SENSOR_VCC = 3V3 / 5V selectable
```

### 本地按钮输入

本地按钮输入建议预留接线柱，即使第一版固件暂时不用，PCB 上留出来后面会很省事：

```text
MANUAL_OPEN
MANUAL_CLOSE
MANUAL_STOP
GND
```

本地按钮输入可以先预留硬件，固件后续再接入。这样网络不可用时仍有本地操作空间。

### RS485 端子

RS485 建议独立一组 3 pin 接线柱：

```text
RS485_A
RS485_B
GND
```

端子旁边建议预留终端电阻跳帽：

```text
120R_TERM_ENABLE
```

如果 PCB 空间允许，也可以把 RS485 的电源一起引出，方便接外部隔离模块或小型从设备：

```text
RS485_A
RS485_B
GND
5V_OUT
```

### 电源输入端子

电源输入也建议用接线柱，不要只依赖 USB：

```text
VIN+
VIN-
PE / SHIELD
```

`PE / SHIELD` 可按现场情况接机箱地、屏蔽层或悬空，至少 PCB 上预留焊盘或端子位置。

### 推荐端子总表

第一版如果想“能接的都留好”，建议至少预留：

| 分组 | 建议端子 |
| --- | --- |
| 电源 | `VIN+`, `VIN-`, `PE/SHIELD` |
| 开继电器 | `OPEN_COM`, `OPEN_NO`, 可选 `OPEN_NC` |
| 关继电器 | `CLOSE_COM`, `CLOSE_NO`, 可选 `CLOSE_NC` |
| 停继电器 | `STOP_COM`, `STOP_NO`, 可选 `STOP_NC` |
| 限位/传感器 | `OPEN_LIMIT`, `CLOSE_LIMIT`, `RAIN_SENSOR`, `EMERGENCY_STOP`, `GND`, `SENSOR_VCC` |
| 本地按钮 | `MANUAL_OPEN`, `MANUAL_CLOSE`, `MANUAL_STOP`, `GND` |
| RS485 | `A`, `B`, `GND`, 可选 `5V_OUT` |

布局上建议把“继电器触点端子”和“低压输入端子”分开放，丝印方向统一朝外，端子边缘留足螺丝刀操作空间。

## 固件后续建议

后续固件可以继续增强：

- 开/关/停脉冲时间配置。
- 雨感极性配置。
- 雨感触发策略配置：仅报警、禁止开顶、自动关顶。
- 急停输入逻辑。
- 输入消抖时间配置。
- 错误状态在 Web 页面明确显示。
- 串口 `STATE` 增加雨感和急停状态。
- RS485 Modbus RTU 扩展。

## JLCEDA 原理图 V1 边界

当前 JLCEDA 原理图建议先按 V1 框架推进，不要急着一次画成最终量产版。

V1 原理图应至少包含：

- ESP32-S3-WROOM-1 主控。
- 三路继电器：`OPEN`, `CLOSE`, `STOP`。
- 三路继电器驱动：MOSFET/三极管、栅极/基极电阻、下拉电阻、反灌二极管、动作 LED。
- 输入接口：开限位、关限位、雨感、急停、本地开/关/停按钮。
- 输入保护：串阻、上拉/下拉、RC 滤波、TVS/ESD 预留位。
- RS485 收发器、A/B/GND 端子、120R 终端电阻跳帽、TVS 预留位。
- 电源：VIN 输入保护、5V 电源、3V3 LDO/降压、必要去耦电容。
- 下载调试：USB-C 或 USB-UART、BOOT、RESET、TX/RX 测试点。

V1 暂不建议直接定死的内容：

- 雨感是否自动关顶。
- RS485 上层协议。
- 限位输入常开/常闭最终极性。
- 外部门机是否需要 `NO` 还是 `NC` 触点。

这些内容更适合等现场控制器、限位开关、雨感模块确定后再锁定。

## 画板前审查清单

原理图转 PCB 前，至少做一轮人工检查：

- ESP32-S3 启动相关引脚没有被外部电路错误拉高/拉低。
- 三路继电器上电默认不吸合。
- 继电器触点侧和 MCU 低压侧保持清楚隔离，不把板上电源误送到外部门机按钮输入。
- 所有外部长线输入都有明确默认电平，不悬空。
- 雨感和限位输入能通过跳帽或焊接位适配常开/常闭、低有效/高有效。
- RS485 A/B 命名在端子、丝印和原理图中一致。
- 120R 终端电阻默认可断开，不强制一直并在总线上。
- 电源输入有反接、过流、浪涌或至少预留保护位。
- 端子边缘留足螺丝刀空间，强弱电区域物理分开。
- 所有接线柱丝印使用功能名，不只写 `J1-1` 这种编号。

## 第一版验收清单

硬件打样后建议至少验证：

- 上电后三路继电器不误动作。
- Web / Alpaca / 串口发开命令时，只有开继电器动作。
- 发关命令时，只有关继电器动作。
- 发停命令时，开/关继电器关闭，停继电器动作。
- 开到位和关到位输入显示正确。
- 两个限位输入异常组合能进入错误状态。
- 雨感输入电平能被稳定读取。
- 急停输入能阻止运动命令。
- WiFi 连接和 OTA 页面可用。
- SPIFFS 默认配置能正常加载。
- RS485 预留脚位没有与现有功能冲突。

## 当前推荐

当前项目最稳的路线是：

```text
主控制：三路继电器干接点
核心反馈：开到位 / 关到位
安全输入：雨感 / 急停
扩展通信：RS485 预留
调试辅助：每路输入输出 LED + USB 串口
```

第一版先把开关量链路做可靠，后续再把 RS485 和更复杂的自动策略加上去。

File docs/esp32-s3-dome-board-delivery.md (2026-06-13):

# ESP32-S3 Dome Board Delivery Index

This is the current PCB delivery snapshot for the ESP32-S3 dome controller V1. As of 2026-05-31, treat it as a production candidate only: the live JLCEDA bridge is not connected, so final JLCEDA UI DRC/export is still pending.

## Current V1 Scope

- Controller: ESP32-S3 module.
- Outputs: three relay dry-contact triggers for `OPEN`, `CLOSE`, and `STOP`.
- Inputs: open limit, close limit, and rain sensor terminals.
- Expansion: RS485 A/B reserved, DNP by default.
- Debug/power: USB-C native ESP32-S3 USB plus external `5V IN` terminal.
- Mounting: four corner M3 NPTH holes.
- Cost target: 2-layer board below `100 mm x 100 mm`, low-cost HASL-compatible first article.
- RF layout: ESP32-S3-WROOM antenna keepout must be left empty: no copper, no traces, no vias, and no components.

The current KiCad V1 board uses external `5V IN` to reduce first-article BOM cost. A future 12/24V input plus buck converter can be added after field power requirements are confirmed.

## Authoritative Artifacts

| Purpose | File |
| --- | --- |
| KiCad offline preview/import baseline | `hardware/kicad/esp32_s3_dome_controller.kicad_pcb` |
| Project file | `hardware/kicad/esp32_s3_dome_controller.kicad_pro` |
| Preview image | `docs/kicad-esp32-s3-dome-controller-preview.svg` |
| JLCEDA outer-IO preview image | `hardware/jlceda/out/pcb3_outer_io_current_simplified.svg.png` |
| Hardware design notes | `docs/esp32-s3-dome-board-hardware.md` |
| Routing/finalization checklist | `docs/pcb2-routing-punchlist.md` |
| Costed V1 BOM draft | `docs/esp32-s3-dome-board-bom.csv` |
| Standard parts assignment | `docs/esp32-s3-dome-board-standard-parts.md` |
| Standard parts machine table | `docs/esp32-s3-dome-board-standard-parts.csv` |
| JLC/LCSC BOM candidate | `docs/esp32-s3-dome-board-jlc-bom.csv` |
| JLC/LCSC source check | `docs/esp32-s3-dome-board-jlc-source-check.md` |
| JLCEDA finish checklist | `docs/esp32-s3-dome-board-jlceda-finish-checklist.md` |
| JLCEDA import and binding notes | `docs/esp32-s3-dome-board-jlceda-import-and-bind.md` |
| Real footprint replacement map | `docs/esp32-s3-dome-board-footprint-map.csv` |
| JLCEDA parts manifest | `docs/esp32-s3-dome-board-jlceda-parts-manifest.csv` |
| Fabrication notes | `docs/esp32-s3-dome-board-fab-notes.md` |
| Strict DRC report | `hardware/kicad/out/drc-errors.rpt` |
| Full DRC report | `hardware/kicad/out/drc.rpt` |
| Gerber/drill preview ZIP | `hardware/kicad/out/esp32_s3_dome_controller_fab_preview.zip` |
| KiCad import ZIP for JLCEDA | `hardware/kicad/out/esp32_s3_dome_controller_kicad_import.zip` |
| Position file | `hardware/kicad/out/esp32_s3_dome_controller_pos.csv` |
| JLCPCB FIT BOM draft | `hardware/kicad/out/jlcpcb_assembly_bom_fit.csv` |
| JLCPCB DNP BOM draft | `hardware/kicad/out/jlcpcb_assembly_bom_dnp.csv` |
| JLCPCB CPL draft | `hardware/kicad/out/jlcpcb_cpl_fit.csv` |
| JLCEDA direct PCB build script | `scripts/jlceda_populate_pcb.mjs` |
| JLCEDA official-pad routing script | `scripts/jlceda_route_official_pads.mjs` |
| JLCEDA final outer-IO routing script | `scripts/jlceda_layout_outer_io_route.mjs` |
| Local static candidate verifier | `scripts/verify_local_board_candidate.mjs` |
| JLCEDA PCB verification script | `scripts/jlceda_verify_pcb3.mjs` |
| JLCEDA LCSC binding verification script | `scripts/jlceda_verify_lcsc_parts.mjs` |
| JLCEDA mounting-hole clearance verification script | `scripts/jlceda_verify_mounting_clearance.mjs` |
| JLCEDA live production gate runner | `scripts/jlceda_apply_and_verify_pcb3_production.mjs` |

## Completion Evidence

| Requirement | Evidence | Status |
| --- | --- | --- |
| Four corner M3 mounting holes | `MH1`..`MH4`, NPTH pads with `3.41 mm` drill in the PCB file | Done |
| Board kept low-cost size | Edge cuts are `91.44 mm x 87.63 mm` | Done |
| 2-layer layout | PCB uses `F.Cu` and `B.Cu` signal layers | Done |
| Three relay outputs | `K1/K2/K3` routed to `J2/J3/J4` dry-contact terminals | Done |
| Rain sensor reserved | `J8 RAIN` terminal routed to `RAIN_GPIO9` | Done |
| 5V input present | `J1 5V IN` terminal and `GND +5V IN` silkscreen | Done |
| USB present | `J9 USB-C DEVICE`, CC pulldowns `R9/R10`, D+/D- routed to ESP32-S3 USB pads | Done |
| Routed without strict KiCad DRC errors | Fresh `hardware/kicad/out/drc-errors-fresh.rpt` reports `0` violations and `0` unconnected pads | Done for KiCad backup |
| Cost optimization documented | JLC BOM marks RS485 and terminator DNP, keeps 2-pin relay terminals, uses native USB, module ESP32-S3, Basic 0603 resistors, and 2-layer board | Done |
| ESP32 antenna keepout called out | `PCB3` includes a document-layer antenna warning rectangle. Current local verifier also warns that the KiCad backup has stale parts/copper in the KiCad antenna rectangle, so KiCad is not an order source. | Needs live PCB3 recheck |
| JLCEDA bridge checked | 2026-05-31 status: `http://127.0.0.1:9151/v1/status` returns `connected:false`; 9050-9059 WS discovery received no extension hello; `jlc-assistant` UI times out and `open -a /Applications/jlc-assistant.app` fails with `-1712`. Log evidence shows `autoSaveInTime: 保存成功` at `2026-05-31 04:21:32`, followed by login-expired `401` at `04:22:19`. `TERM` and `KILL` did not release the stuck `UE` process. | Blocked for live JLCEDA verification |
| JLCEDA floating schematic page cleaned | JLCEDA page `4f59e624d870fc29` was rebuilt via `jlceda-mcp-bridge` with 30 JLC/LCSC components and 7 aligned section notes; snapshot confirmed the component count | Done as schematic/BOM anchor |
| JLCEDA linked schematic source cleaned | Linked board `Board3_1` uses `Schematic3`; page `P1` / UUID `018b50bd6ee3ee7a` is deprecated and has been cleared to the drawing sheet only | Done |
| JLCEDA linked schematic populated | Formal source page is `P2.Schematic3` / UUID `227f009d50838569`; readback confirmed the 30 PCB designators `K1/K2/K3`, `J1`..`J9`, `U1/U2/U3`, `Q1`..`Q3`, `D1`..`D3`, `R1`..`R6`, and `R8/R9/R10`, with no extra part designators | Done as linked schematic |
| JLCEDA linked PCB created | `PCB3` UUID `5664b0722a0b08df` is linked under `Board3_1` | Created, not imported |
| JLCEDA PCB import from schematic | Earlier `pcb_Document.importChanges("720bbc0db4383d2e")` and default `pcb_Document.importChanges()` returned `false`; after P2 cleanup, `pcb_Document.importChanges("227f009d50838569")` returned `true`, but JLCEDA still reports one `Netlist Error / Import Changes` item | Physical PCB is verified; UI netlist sync remains an order gate |
| JLCEDA direct PCB build | `scripts/jlceda_populate_pcb.mjs` populated `PCB3` with 30 real JLC/LCSC components, board outline, four M3 holes, 199 line primitives, and 26 vias; JLCEDA UI shows the board on `PCB3` | Superseded by official-pad routing |
| JLCEDA final outer-IO routing script | `scripts/jlceda_layout_outer_io_route.mjs` keeps USB-C on the bottom edge, field terminals on board edges, and now places `R1/R2` at `x=2130mil` to give more margin from the relay body while staying outside the antenna warning area. | Script updated; rerun on PCB3 when bridge reconnects |
| JLCEDA live production gate runner | `scripts/jlceda_apply_and_verify_pcb3_production.mjs` runs the local static check, applies the current PCB3 layout/routing script, runs all PCB3 readback checks, then runs P2 import plus JLCEDA PCB DRC. With the current disconnected bridge it fails before any live write. | Ready; blocked on bridge |
| JLCEDA PCB readback | Previous readback from `scripts/jlceda_verify_pcb3.mjs` reported 30 components, no missing/extra expected designators, 298 line primitives, 12 strings, and no listed support parts inside the antenna warning area. | Must rerun after applying current script |
| JLCEDA mounting clearance | `scripts/jlceda_verify_mounting_clearance.mjs` reported `componentHitCount: 0`, `lineHitCount: 0`, and `viaHitCount: 0` around `MH1`..`MH4` | Done |
| JLCEDA connectivity | `scripts/jlceda_find_open_nets_layered.mjs` reported `openNetCount: 0` | Done |
| JLCEDA local clearance scan | `scripts/jlceda_check_clearance.mjs` reported `lineHitCount: 0`, `lineLineHitCount: 0`, `lineViaHitCount: 0`, and `viaHitCount: 0` | Done |
| JLCEDA LCSC bindings | `scripts/jlceda_verify_lcsc_parts.mjs` reported all 30 components match expected LCSC supplier IDs; `J5/R8/U2` are excluded from BOM by default | Done |
| JLCEDA P2 relay/PCB net alignment | P2 was corrected for `K1/K2/K3` relay pinout, `J5` RS485 A/B, `U1` EN/USB D+/D-, `U3.2`, and `J9` shell GND; direct Ref.Pin readback confirmed `103` P2 pins with nets match the `103` PCB3 pads with nets, with mismatch/schematic-only/PCB-only counts all `0` | Done |
| Standard parts assigned | `docs/esp32-s3-dome-board-standard-parts.md` and `.csv` fix the V1 FIT/DNP policy, LCSC numbers, package choices, substitution gates, and order gates | Done |
| JLCEDA PCB DRC via bridge | `pcb_Drc.check(true, false, true)` still reports one generic `Netlist Error / Import Changes` item after import retries, while direct P2-vs-PCB Ref.Pin comparison and `sys_Tool.netlistComparison` show no concrete net differences | Physical PCB and source nets match; clear stale UI netlist item before order export |
| Local static candidate check | `node scripts/verify_local_board_candidate.mjs` confirms P2/PCB3 UUIDs, no active P1 use, edge connector placement, M3 hole coordinates, revised R1/R2 script placement, R1/R2 relay-body margins, and key KiCad relay/MOSFET/flyback/USB/5V/limit/rain pad nets. It warns that the KiCad backup antenna area is stale. | Passes with KiCad-stale warnings |

## Production Gate

The board is not cleared for ordering until the live JLCEDA checks below pass. `PCB3` remains the intended production candidate, but the current R1/R2 script adjustment has not been applied or re-read from the live JLCEDA canvas in this session.

- Re-check live stock/class for the LCSC numbers in `docs/esp32-s3-dome-board-standard-parts.md` and `docs/esp32-s3-dome-board-jlc-bom.csv` before ordering.
- For the MCP-created JLCEDA working set, continue from `Board3_1` / `Schematic3` page `P2` / `PCB3`; keep `P1` cleared and do not use it as a source page.
- Place `U1` with the ESP32-S3-WROOM-1 antenna facing a board edge and keep the marked antenna keepout empty: no copper pour, no tracks, no vias, no components, and no metal mounting hardware.
- Confirm the selected USB-C receptacle footprint against the part ordered.
- Confirm relay footprint pinout against the exact relay ordered.
- Re-run JLCEDA UI DRC after synchronizing/importing the schematic netlist, and keep `全部 (0)` before ordering.
- Re-run `scripts/jlceda_apply_and_verify_pcb3_production.mjs`; it wraps the current layout script, all PCB3 readback checks, P2 import, and JLCEDA PCB DRC gate in the required order.
- Export Gerber, drill, position, and BOM directly from JLCEDA `PCB3` for the real order package.

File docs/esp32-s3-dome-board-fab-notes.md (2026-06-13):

# ESP32-S3 Dome Board Fabrication Notes

## Board Target

- Board size: `91.44 mm x 87.63 mm`.
- Layer count: 2 layers.
- Thickness: `1.6 mm`.
- Copper: `1 oz` is enough for the relay coil and low-voltage signal version.
- Finish: HASL is acceptable for the low-cost first article; ENIG is not required.
- Mounting: four corner M3 NPTH holes, drill about `3.4 mm`.
- ESP32 antenna: keep the module antenna area empty on all copper layers; no traces, vias, copper pour, metal mounting hardware, or components under/in front of the antenna.

## Do Not Order Before These Checks

- Use the JLCEDA `PCB3` production candidate, not the KiCad preview, for the official order package.
- If the KiCad baseline is used for a fresh import, replace every `Codex:*` placeholder footprint with the real JLCEDA/LCSC footprint before ordering.
- When replacing `U1`, use the official ESP32-S3-WROOM-1 keepout and orient the antenna toward a board edge.
- Confirm the selected USB-C connector shell pads, locator holes, and board-edge direction.
- Confirm the selected relay pinout against `K1/K2/K3`; Songle SRD-style relays have common variants.
- Confirm terminal block pitch and screw direction before ordering the PCB.
- Re-run DRC after footprint replacement and keep strict errors at `0`.

## Low-Cost Assembly Choices

- Keep RS485 parts DNP in V1 unless the field wiring really needs it.
- Keep relay outputs as 2-pin `COM/NO` terminals unless `NC` is confirmed necessary.
- Use ESP32-S3 module instead of bare ESP32-S3 chip to avoid RF layout and extra passives.
- Use native ESP32-S3 USB through USB-C; do not add a USB-UART chip.
- Use one resistor package family. For JLC assembly, prefer the Basic 0603 parts listed in `docs/esp32-s3-dome-board-jlc-bom.csv`; switch to 0805 only if hand rework is more important than assembly cost.
- Keep external power as `5V IN` for V1; adding 12/24V buck input is a later cost/function tradeoff.

## Exported Files

- PCB preview: `docs/kicad-esp32-s3-dome-controller-preview.svg`
- DRC strict-error report: `hardware/kicad/out/drc-errors.rpt`
- Full DRC report: `hardware/kicad/out/drc.rpt`
- Gerber/drill preview ZIP: `hardware/kicad/out/esp32_s3_dome_controller_fab_preview.zip`
- Position CSV: `hardware/kicad/out/esp32_s3_dome_controller_pos.csv`
- JLC/LCSC BOM candidate: `docs/esp32-s3-dome-board-jlc-bom.csv`
- JLCPCB FIT BOM draft: `hardware/kicad/out/jlcpcb_assembly_bom_fit.csv`
- JLCPCB DNP list: `hardware/kicad/out/jlcpcb_assembly_bom_dnp.csv`
- JLCPCB CPL draft: `hardware/kicad/out/jlcpcb_cpl_fit.csv`
- JLCEDA finish checklist: `docs/esp32-s3-dome-board-jlceda-finish-checklist.md`

The KiCad Gerber/drill ZIP is a preview package for checking layers, holes, outline, and routing. The intended order source is JLCEDA `PCB3`, not the KiCad preview. Earlier live `PCB3` checks showed LCSC parts, edge-facing USB-C, outer-edge terminals, clean M3 mounting-hole clearances, and no physical PCB DRC clearance/connection errors; however, the current `R1/R2` margin adjustment has not been applied/read back because the JLCEDA bridge is disconnected. Before ordering, reconnect the bridge, rerun the current routing script, clear the remaining generic JLCEDA UI `Netlist Error / Import Changes` item, and re-run JLCEDA DRC/export from `PCB3`.

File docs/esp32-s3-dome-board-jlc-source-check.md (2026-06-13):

# JLC/LCSC Part Source Check

Checked against JLCPCB part-detail pages and JLCEDA library readback. Stock and Basic/Extended class can change, so re-check in JLCEDA before ordering.

| Function | LCSC | MPN / Keyword | JLCPCB page |
| --- | --- | --- | --- |
| ESP32-S3 module | C2913201 | ESP32-S3-WROOM-1-N8R8 | JLCEDA library search |
| 3.3 V LDO | C6186 | AMS1117-3.3 | https://jlcpcb.com/partdetail/AMS1117-33-C6186 |
| RS485 transceiver | C8963 | SP3485EN-L/TR | https://jlcpcb.com/partdetail/Sipex_SP3485EN-L-TR/C8963 |
| Relay | C35449 | SRD-05VDC-SL-C | https://jlcpcb.com/partdetail/SRDSongleRelay-SRD05VDCSLC/C35449 |
| N-MOSFET | C20917 | AO3400A | https://jlcpcb.com/partdetail/ChangjiangMicroelectronics-AO3400A/C20917 |
| Flyback diode | C81598 | 1N4148W | https://jlcpcb.com/partdetail/DiodesIncorporated-1N4148W7F/C81598 |
| 100R resistor | C22775 | 0603 100R | https://jlcpcb.com/partdetail/UNI_ROYAL-UniroyalElec0603WAF1000T5E/C22775 |
| 10k resistor | C25804 | 0603 10k | https://jlcpcb.com/partdetail/UNI_ROYAL-UniroyalElec0603WAF1002T5E/C25804 |
| 120R resistor | C22787 | 0603 120R | https://jlcpcb.com/partdetail/UNI_ROYAL-UniroyalElec0603WAF1200T5E/C22787 |
| 5.1k resistor | C23186 | 0603 5.1k | https://jlcpcb.com/partdetail/UNI_ROYAL-UniroyalElec0603WAF5101T5E/C23186 |
| 5.08 mm terminal | C8465 | WJ500V-5.08-2P | JLCEDA library search |
| 3.81 mm terminal | C9900005589 | KF128-3.81-2P | JLCEDA library search |
| USB-C receptacle | C165948 | HRO TYPE-C-31-M-12 | https://jlcpcb.com/partdetail/HRO-TYPEC31M12/C165948 |

## Notes

- KiCad remains a preview/import baseline and still contains local `Codex:*` footprints. The current JLCEDA production candidate is `ascom_dome` / `PCB3`.
- Earlier live readback with `scripts/jlceda_verify_lcsc_parts.mjs` confirmed all 30 `PCB3` components had `supplier: LCSC` plus the expected `supplierId`; `U2`, `R8`, and `J5` are intentionally `addIntoBom: false`.
- `jlceda-mcp-bridge` was connected earlier with JLCEDA Pro `3.2.135`, but the current 2026-05-31 bridge status is disconnected and must be recovered before order export; see `docs/esp32-s3-dome-board-jlceda-import-and-bind.md`.
- Before ordering, re-check live stock/class in JLCEDA/JLCPCB and verify USB-C shell pads, relay pinout, terminal direction, and ESP32 antenna keepout one last time.

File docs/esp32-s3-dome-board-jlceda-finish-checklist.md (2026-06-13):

# JLCEDA Finish Checklist

Use this checklist to review the current JLCEDA `PCB3` production candidate with JLC/LCSC parts. As of 2026-05-31, this checklist is not complete because the local JLCEDA bridge is disconnected.

## Import / Rebuild

1. Open or recreate the board in JLCEDA Pro.
2. Continue from project `ascom_dome` / board `Board3_1` / PCB `PCB3`.
3. Use `docs/esp32-s3-dome-board-standard-parts.md` and `docs/esp32-s3-dome-board-standard-parts.csv` as the standard FIT/DNP and substitution authority.
4. Use `docs/esp32-s3-dome-board-jlc-bom.csv` as the current grouped LCSC BOM candidate.
5. Use `docs/esp32-s3-dome-board-jlceda-parts-manifest.csv` for confirmed device, symbol, and footprint UUIDs found through `jlceda-mcp-bridge`.
6. Use `docs/esp32-s3-dome-board-jlceda-import-and-bind.md` for import notes and JLCEDA bridge evidence.
7. Keep the KiCad board geometry as the reference:
   - Board size: `91.44 mm x 87.63 mm`.
   - Four M3 NPTH holes: `3.41 mm` drill around the four corners.
   - Relay terminals on the right edge.
   - Input terminals on the top edge.
   - `5V IN` and USB-C near the bottom edge.

## Current MCP Working Set

- Continue from JLCEDA project `ascom_dome`.
- Preferred linked working set: `Board3_1`.
- Schematic source: `Schematic3`, page `P2`, UUID `227f009d50838569`.
- Deprecated schematic page: `P1`, UUID `018b50bd6ee3ee7a`, kept as drawing sheet only with no parts, wires, or extra text.
- PCB target: `PCB3`, UUID `5664b0722a0b08df`.
- The linked schematic has the real JLC/LCSC devices placed. Earlier linked-schematic import calls returned `false`; after the P2 cleanup, `pcb_Document.importChanges("227f009d50838569")` returned `true`, but JLCEDA still keeps one `Netlist Error / Import Changes` DRC item.
- `scripts/jlceda_populate_pcb.mjs` manually rebuilt `PCB3` from the KiCad geometry using real JLC/LCSC device components.
- `scripts/jlceda_layout_outer_io_route.mjs` is the current routing script: USB-C faces the bottom edge, screw terminals are near board edges, and `R1/R2` are now set to `x=2130mil` so they sit between the ESP32 antenna warning area and the relay body instead of under the relay body. Rerun this script on `PCB3` after the bridge reconnects.
- `scripts/jlceda_apply_and_verify_pcb3_production.mjs` is the live production gate runner. After the bridge reconnects, run it to apply the current PCB3 script, rerun all readback checks, import from P2, and execute JLCEDA PCB DRC before export.
- `P2.Schematic3` readback evidence: 30 formal part designators, no missing/extra expected PCB refs, USB-C `J9`, and CC pulldowns `R9/R10` present.
- Previous `scripts/jlceda_verify_pcb3.mjs` readback evidence: 30 components, no missing/extra expected designators, 298 line primitives, 12 strings, and no listed support parts inside the broad antenna warning area. This must be rerun after applying the current R1/R2 script adjustment.
- `scripts/jlceda_verify_mounting_clearance.mjs` readback evidence: the four M3 holes `MH1`..`MH4` have no component, copper line, or via hits inside the configured mounting clearance radii.
- `scripts/jlceda_find_open_nets_layered.mjs` readback evidence: `openNetCount: 0`.
- `scripts/jlceda_check_clearance.mjs` readback evidence: line/pad, line/line, line/via, and via/via hit counts are all `0`.
- `scripts/jlceda_verify_lcsc_parts.mjs` readback evidence: all 30 PCB components use `supplier: LCSC` with the expected `supplierId`; `U2`, `R8`, and `J5` are excluded from BOM by default.
- `docs/esp32-s3-dome-board-standard-parts.md` and `.csv` evidence: V1 standard parts are assigned, RS485 remains default DNP, and substitutions are constrained by footprint/pinout gates.
- Direct JLCEDA PCB DRC evidence before the current script-only `R1/R2` margin adjustment: `pcb_Drc.check(true, false, true)` reported only one `Netlist Error / Import Changes` item and no clearance, slot, connection, or open-copper physical errors. Rerun this after the bridge reconnects and the current routing script is applied.
- Schematic DRC evidence: `jlc.schematic.drc({ strict:false, userInterface:false })` returned `ok:true` after the P1/P2 cleanup.
- P2 net alignment evidence: P2 was corrected for `K1/K2/K3` relay pinout, `J5` RS485 A/B, `U1` EN/USB D+/D-, `U3.2`, and `J9` shell GND; direct Ref.Pin readback confirmed `103` P2 pins with nets match the `103` PCB3 pads with nets, with mismatch/schematic-only/PCB-only counts all `0`.
- Remaining order-gate item: JLCEDA PCB DRC still reports a generic `Netlist Error / Import Changes` after import retries even though direct Ref.Pin net comparison is clean; clear this UI netlist item and re-run `检查DRC` before generating order files.
- Current live-bridge gate: on 2026-05-31, `http://127.0.0.1:9151/v1/status` reports `connected:false`, 9050-9059 discovery receives no extension `hello`, the `jlc-assistant` app UI times out, and `open -a /Applications/jlc-assistant.app` fails with `-1712`. JLCEDA logs show `autoSaveInTime: 保存成功` at `2026-05-31 04:21:32`, followed by login-expired `401` at `04:22:19`; `TERM` and `KILL` did not release the stuck `UE` process. Do not export/order until this is recovered and all PCB3 scripts/DRC are rerun.

## Critical Layout Gates

- ESP32-S3-WROOM-1 antenna side faces a board edge.
- ESP32 antenna keepout has no copper, no tracks, no vias, no components, and no metal mounting hardware.
- Treat the KiCad `Dwgs.User` antenna rectangle as a hard placement warning. The official EasyEDA ESP32-S3-WROOM-1 footprint may shift the exact antenna end slightly, so re-center the no-copper/no-part zone on the real module antenna before final DRC.
- Input pullups and relay driver support parts `Q1/Q2/R1/R2/R4/R5/R6` are intended to stay out of the broad antenna warning area in `PCB3`; the current local script keeps `R1/R2` pulled toward the MOSFET side, but live `PCB3` readback is still required.
- The KiCad backup is stale for antenna-area verification: `node scripts/verify_local_board_candidate.mjs` reports KiCad backup parts/copper in the KiCad antenna rectangle. Use KiCad only as a mechanical/import baseline, not as an order source.
- USB-C connector shell/locator holes match `C165948`.
- Relay pinout matches `C35449` before routing coil and contact pads.
- Terminal screw direction faces outward for field wiring.
- Relay dry-contact outputs remain isolated from ESP32 GND and 5V.
- RS485 parts `U2`, `R8`, and `J5` remain DNP unless the first build needs RS485.

## Cost Gates

- Keep the board 2-layer.
- Use HASL unless there is a clear reason to pay for ENIG.
- Use Basic 0603 resistors where listed:
  - `C22775` 100R
  - `C25804` 10k
  - `C22787` 120R DNP
  - `C23186` 5.1k
- Do not add a USB-UART chip; ESP32-S3 native USB is already routed.
- Do not expand relay terminals to 3P unless `NC` is required in the field.
- Keep `U2`, `R8`, and `J5` DNP unless the first build intentionally includes RS485.

## Files for JLCPCB Assembly Upload

- JLCEDA production candidate: project `ascom_dome` / `Board3_1` / `PCB3`.
- Current final routing script: `scripts/jlceda_layout_outer_io_route.mjs`.
- Live production gate runner: `scripts/jlceda_apply_and_verify_pcb3_production.mjs`.
- Local static candidate verifier: `scripts/verify_local_board_candidate.mjs`.
- Standard parts assignment: `docs/esp32-s3-dome-board-standard-parts.md` and `docs/esp32-s3-dome-board-standard-parts.csv`.
- Confirmed JLCEDA parts manifest: `docs/esp32-s3-dome-board-jlceda-parts-manifest.csv`.
- KiCad preview Gerber/drill ZIP: `hardware/kicad/out/esp32_s3_dome_controller_fab_preview.zip`.
- KiCad import ZIP for JLCEDA: `hardware/kicad/out/esp32_s3_dome_controller_kicad_import.zip`.
- KiCad FIT/DNP/CPL drafts remain useful cross-checks, but the order package should be regenerated from JLCEDA `PCB3`.

These upload files are generated from the KiCad baseline. For ordering, regenerate the official JLCEDA Gerber/BOM/CPL from `PCB3` only after the live bridge reconnects, the current routing script is applied, and JLCEDA DRC reports zero remaining items.

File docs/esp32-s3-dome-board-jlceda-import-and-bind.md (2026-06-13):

# JLCEDA Import and Binding Notes

Use this note when moving the KiCad baseline into JLCEDA Pro for the final production version. The KiCad files are an offline preview/import baseline; the order source must be JLCEDA `PCB3` after live DRC passes.

## MCP Bridge Status

The local `jlceda-mcp-bridge` was tested again on 2026-05-30 and again on 2026-05-31:

- Bridge URL: `http://127.0.0.1:9151`
- JLCEDA extension app: `jlceda-mcp-bridge`
- Bridge version: `0.0.17`
- JLCEDA Pro version reported by the bridge: `3.2.135`
- 2026-05-30 bridge status: connected during earlier verification
- 2026-05-31 bridge status: HTTP bridge is listening, but `connected:false`; 9050-9059 discovery receives no extension `hello`; `jlc-assistant` UI access times out
- Current JLCEDA documents checked: linked schematic page `P2.Schematic3` / UUID `227f009d50838569`, and linked PCB `PCB3` / UUID `5664b0722a0b08df`

The bridge supports schematic placement/query/export helpers and generic `eda` API calls. The exposed MCP tool set did not provide a complete high-level PCB autorouting/import flow, so V1 was finished by direct PCB primitive placement/routing in `PCB3`:

1. Place the confirmed official JLC/LCSC devices in the linked schematic and PCB.
2. Rebuild `PCB3` with official EasyEDA footprints through `scripts/jlceda_populate_pcb.mjs` when starting from an empty board.
3. Use `scripts/jlceda_layout_outer_io_route.mjs` for the current placement/routing: USB-C on the bottom edge, field terminals on board edges, relay contacts on the right edge, revised `R1/R2` placement at `x=2130mil`, and no copper/vias/parts in the ESP32 antenna warning area.
4. After the bridge reconnects, run `scripts/jlceda_apply_and_verify_pcb3_production.mjs` to apply the current PCB3 script, rerun all readback checks, import from `P2.Schematic3`, and execute the JLCEDA PCB DRC gate in one sequence.
5. Re-check placement, especially USB-C, relay pins, terminal orientation, and the ESP32 antenna area.
6. Re-run JLCEDA DRC and export the official production Gerber/BOM/CPL from JLCEDA.

## Applied JLCEDA Pages

The first JLCEDA schematic page was cleaned and rebuilt through `jlceda-mcp-bridge` on 2026-05-29:

- Cleared old sketch content: 73 text primitives and 31 components.
- Created 30 components from JLC/LCSC library devices.
- Created 7 aligned section/title notes.
- Saved successfully through the JLCEDA schematic save API.
- Snapshot after placement reported 30 components and 7 text notes.

That page is a clean component-placement/BOM anchor for the design, but it is a floating schematic and not the production PCB source.

The current linked JLCEDA working set is:

- Project: `ascom_dome`, UUID `71d1661872f843fda19343ed40390dcb`
- Linked board: `Board3_1`, UUID `d4f25f5d90f995f8`
- Linked schematic: `schematic3`, UUID `720bbc0db4383d2e`
- Deprecated schematic page: `P1`, UUID `018b50bd6ee3ee7a`; this page has been cleared and now contains only the drawing sheet.
- Formal schematic source page: `P2`, UUID `227f009d50838569`
- Linked PCB: `PCB3`, UUID `5664b0722a0b08df`

The formal linked schematic page `227f009d50838569` is the production source. It was cleaned to the A4 drawing frame/title block, duplicate text notes were removed, and USB-C source parts were added. Verified designators now match `PCB3`: `U1 U2 U3`, `K1 K2 K3`, `J1 J2 J3 J4 J5 J6 J7 J8 J9`, `Q1 Q2 Q3`, `D1 D2 D3`, `R1 R2 R3 R4 R5 R6 R8 R9 R10`. `J9` carries `5V`, `GND`, `USB_D+`, `USB_D-`, `USB_CC1`, and `USB_CC2` labels; `R9/R10` are the 5.1k CC pulldowns.

PCB import status: `PCB3` is linked to `schematic3`. Earlier `pcb_Document.importChanges("720bbc0db4383d2e")` and default `pcb_Document.importChanges()` calls returned `false` through the bridge, so the linked PCB was completed by manual MCP rebuild instead of schematic import. After the P1/P2 cleanup, `pcb_Document.importChanges("227f009d50838569")` returned `true`, but the JLCEDA PCB DRC still retains one `Netlist Error / Import Changes` item; clear that UI netlist item before order export.

## Direct PCB Build Attempt

Because `pcb_Document.importChanges` did not accept the linked schematic, the current PCB was populated directly through JLCEDA PCB primitive APIs on 2026-05-29.

- Script: `scripts/jlceda_populate_pcb.mjs`
- Target: `PCB3`, UUID `5664b0722a0b08df`
- Method: placed real JLC/LCSC device components with `pcb_PrimitiveComponent.create`, then transferred board outline, M3 holes, KiCad routed segments, vias, and component pad net names into JLCEDA PCB coordinates.
- Coordinate conversion: JLCEDA PCB API uses mil-scale data coordinates; KiCad mm coordinates were converted by `mil = mm * 1000 / 25.4`.
- Readback evidence after cleanup:
  - Components: 30
  - Lines: 199
  - Vias: 26
  - Designators: `U1 U2 U3`, `K1 K2 K3`, `J1 J2 J3 J4 J5 J6 J7 J8 J9`, `Q1 Q2 Q3`, `D1 D2 D3`, `R1 R2 R3 R4 R5 R6 R8 R9 R10`
- Earlier UI evidence: JLCEDA Pro was open on `ascom_dome | PCB3 | 嘉立创EDA(专业版) - V3.2.135`, and the board geometry/components/routes were visible in the PCB canvas. On 2026-05-31 the app is not reachable through the bridge/UI automation, so this must be rechecked live before ordering.

The first direct transfer was not DRC clean. A strict JLCEDA PCB DRC run reported:

- Clearance Error: 229
- Connection Error: 57
- Netlist Error: 1

Primary inferred cause: the KiCad baseline used simplified placeholder footprints, especially for the ESP32-S3 module. The direct conversion used real JLCEDA footprints, so some placeholder-route endpoints no longer lined up with the official pads.

## Final Outer-IO PCB Routing

`PCB3` was then re-routed against the actual JLCEDA footprint pad coordinates and the requested outer-edge connector placement. On 2026-05-31 the local routing script was tightened further so `R1/R2` move from `x=2180mil` to `x=2130mil`; this script change still needs to be applied to the live `PCB3` document after the bridge reconnects.

- Script: `scripts/jlceda_layout_outer_io_route.mjs`
- Target: `PCB3`, UUID `5664b0722a0b08df`
- Method: delete old PCB lines/vias/strings, move USB-C and terminal blocks to the board edges, keep `J1/J6/J7/J8` clear of the four M3 mounting-hole keepout areas, read each official footprint pad coordinate with `pcb_PrimitiveComponent.getAllPinsByPrimitiveId`, recreate two-layer routed line primitives on the intended nets, and save the board.
- Previous readback evidence from `scripts/jlceda_verify_pcb3.mjs`:
  - Components: 30
  - Missing expected refs: none
  - Extra refs: none
  - Line primitives: 298
  - Vias: 29
  - Silkscreen/document strings: 12
  - Support parts inside the broad ESP32 antenna warning rectangle: none for `Q1 Q2 R1 R2 R4 R5 R6`
  - Expected designators: `U1 U2 U3`, `K1 K2 K3`, `J1 J2 J3 J4 J5 J6 J7 J8 J9`, `Q1 Q2 Q3`, `D1 D2 D3`, `R1 R2 R3 R4 R5 R6 R8 R9 R10`
- Connectivity evidence from `scripts/jlceda_find_open_nets_layered.mjs`: `openNetCount: 0`.
- Local clearance evidence from `scripts/jlceda_check_clearance.mjs`: line/pad, line/line, line/via, and via/via hit counts are all `0`.
- Mounting clearance evidence from `scripts/jlceda_verify_mounting_clearance.mjs`: component, copper line, and via hit counts around `MH1`..`MH4` are all `0`.
- LCSC binding evidence from `scripts/jlceda_verify_lcsc_parts.mjs`: all 30 components use the expected `supplier: LCSC` and `supplierId`; `J5`, `R8`, and `U2` are excluded from BOM by default.
- Direct JLCEDA PCB DRC evidence before the 2026-05-31 script-only R1/R2 margin adjustment: `pcb_Drc.check(true, false, true)` reported only one `Netlist Error / Import Changes` item and no clearance, slot, connection, or open-copper physical errors. Rerun DRC after applying the current script.
- P2 net alignment evidence: P2 was corrected for `K1/K2/K3` relay pinout, `J5` RS485 A/B, `U1` EN/USB D+/D-, `U3.2`, and `J9` shell GND; direct Ref.Pin readback confirmed `103` P2 pins with nets match the `103` PCB3 pads with nets, with mismatch/schematic-only/PCB-only counts all `0`.
- Remaining order-gate item: DRC still reports one generic `Netlist Error / Import Changes` item after default import, linked schematic import, and `pcb_Document.importChanges("227f009d50838569")` all returned `true`; clear this JLCEDA UI netlist item and re-run `检查DRC` before order export.
- Layout cleanup: `Q1/Q2/R1/R2/R4/R5/R6` are intended to be out of the broad ESP32 antenna warning area, `R1/R2` are pulled back to the MOSFET side and rotated 180 degrees so they do not sit under the relay body area, U1 `3V3` is explicitly routed, USB-C VBUS/GND pads are tied into the board 5V/GND nets, USB-C VBUS/CC escape is adjusted to clear the connector pads and mechanical slot, and non-bus signal routes use 45-degree chamfered corners.

Bridge note: direct `pcb_Drc.check` RPC is usable only when the JLCEDA client bridge is connected. The current 2026-05-31 local state is disconnected, so the remaining generic netlist item and the current R1/R2 script placement both remain order-export gates until live readback passes.

## Import Package

Create or use:

`hardware/kicad/out/esp32_s3_dome_controller_kicad_import.zip`

Expected contents:

- `esp32_s3_dome_controller.kicad_pcb`
- `esp32_s3_dome_controller.kicad_pro`
- `fp-lib-table`
- `Codex.pretty/*.kicad_mod`

In JLCEDA Pro, use the KiCad import entry and select the ZIP. After import, use the KiCad layout as geometry reference, not as final production footprints.

## Confirmed LCSC / EasyEDA Footprints

These were checked through `jlceda-mcp-bridge` library search.

The machine-readable manifest is:

`docs/esp32-s3-dome-board-jlceda-parts-manifest.csv`

| Ref | LCSC | MPN | EasyEDA footprint | Footprint UUID | Fit |
| --- | --- | --- | --- | --- | --- |
| U1 | C2913201 | ESP32-S3-WROOM-1-N8R8 | `WIRELM-SMD_ESP32-S3-WROOM-1` | `bacdc9b3530d4b9ca5f35adac008b474` | FIT |
| U3 | C6186 | AMS1117-3.3 | `SOT-223-3_L6.5-W3.4-P2.30-LS7.0-BR` | `20c29e37a9b84b4197418483096f9c05` | FIT |
| U2 | C8963 | SP3485EN-L/TR | `SOIC-8_L5.0-W4.0-P1.27-LS6.0-BL` | `f7d15c2fdb6442c7924d73bb1cadcb47` | DNP by default |
| K1 K2 K3 | C35449 | SRD-05VDC-SL-C | `RELAY-TH_SRD-XXVDC-XL-C` | `e091fe638fa34354809b87cd801cad53` | FIT |
| Q1 Q2 Q3 | C20917 | AO3400A | `SOT-23-3_L2.9-W1.3-P1.90-LS2.4-BR` | `bdad16194d454cb292a50525f39c3ffd` | FIT |
| D1 D2 D3 | C81598 | 1N4148W | `SOD-123F_L2.7-W1.6-LS3.8-RD` | `9037e46ec88e4daaac06215d79f5d775` | FIT |
| R1 R2 R3 | C22775 | 0603WAF1000T5E | `R0603` | `50b4943912284dab97752312e589e9e2` | FIT |
| R4 R5 R6 | C25804 | 0603WAF1002T5E | `R0603` | `50b4943912284dab97752312e589e9e2` | FIT |
| R8 | C22787 | 0603WAF1200T5E | `R0603` | `50b4943912284dab97752312e589e9e2` | DNP by default |
| R9 R10 | C23186 | 0603WAF5101T5E | `R0603` | `50b4943912284dab97752312e589e9e2` | FIT |
| J1 J2 J3 J4 | C8465 | WJ500V-5.08-2P | `CONN-TH_2P-P5.00_WJ500V-5.08-2P` | `8968bbc397b14e199797e74eee3df70d` | FIT |
| J5 | C9900005589 | KF128-3.81-2P | `CONN-TH_P3.81_KF128L-3.81-2P-1` | `487be35cd79947a0b5f4b62e4888dd6b` | DNP by default |
| J6 J7 J8 | C9900005589 | KF128-3.81-2P | `CONN-TH_P3.81_KF128L-3.81-2P-1` | `487be35cd79947a0b5f4b62e4888dd6b` | FIT |
| J9 | C165948 | TYPE-C-31-M-12 | `USB-C_SMD-TYPE-C-31-M-12_1` | `6be549a13f5d4c07a7d9efa614d32ed9` | FIT |

Notes:

- Searching exact `C35449` once returned unrelated header results; searching `SRD-05VDC-SL-C` returned the correct relay with supplier part `C35449`.
- Searching `C2913204` returns the N8R2 module. Searching `ESP32-S3-WROOM-1-N8R8` returns `C2913201`, so the V1 BOM uses `C2913201` for the N8R8 variant.
- The previous `C8463` candidate is a 5.0 mm terminal in the current JLCEDA library, not the desired 3.81 mm terminal. The V1 low-voltage terminals now use `C9900005589` / `KF128-3.81-2P`.
- Re-check stock, Basic/Extended class, and footprint availability in JLCEDA immediately before ordering.

## Final PCB Gates

- Board remains 2-layer and below `100 mm x 100 mm`.
- Four corner M3 NPTH mounting holes stay clear of copper and field wiring.
- USB-C and external `5V IN` are both present.
- ESP32-S3 antenna side faces the board edge.
- The final ESP32 antenna keepout has no copper pour, no tracks, no vias, no components, and no metal mounting hardware.
- Relay outputs are dry contacts only; they do not connect field-side output terminals to ESP32 GND or board 5V.
- RS485 parts remain DNP unless the first production build needs RS485.
- Direct JLCEDA PCB DRC must be rerun after the bridge reconnects and the current routing script is applied. Prefer `scripts/jlceda_apply_and_verify_pcb3_production.mjs` for this gate. Do not order while the bridge is disconnected or while any JLCEDA UI DRC item remains.

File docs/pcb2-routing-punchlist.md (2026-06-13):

# PCB2 布线收尾清单

本文记录 ESP32-S3 平移顶控制板 `PCB2` 的剩余布线工作，方便 JLCEDA 客户端恢复后继续按同一个方向收线，不重复走弯路。

## 目标

- 2 层板，尺寸控制在 `100 mm x 100 mm` 内。
- 四角预留 M3 非金属化安装孔，孔径约 `3.2 mm`。
- 电源、继电器干接点、限位输入、雨感输入、RS485 预留都靠板边用接线柱引出。
- V1 主控制链路使用 `OPEN`、`CLOSE`、`STOP` 三路继电器干接点。
- RS485 仅预留，`R8 120R` 终端电阻在 V1 默认 DNP。

## 当前稳定基线

JLCEDA 客户端卡死前，最后一次稳定 DRC 为：

```text
Connection Error: 31
GND: 21
3V3: 4
OPEN_COIL_LOW: 2
RS485_A: 2
RS485_B: 2
```

该基线没有 clearance 或 physical 类 DRC 错误。

KiCad 离线备份板已经进一步整理，当前 DRC 状态为：

```text
短路/交叉/clearance/hole-clearance/solder-mask-bridge: 0
未连接: 0
严格错误检查: 0
完整 DRC 警告: 34 条 lib_footprint_mismatch
```

已补充内容：

- `J9 USB-C DEVICE`：ESP32-S3 原生 USB 下载/调试口，VBUS 接 5V，D+/D- 接 MCU USB 引脚，CC1/CC2 各用 5.1k 下拉。
- `J1 5V IN`：外部 5V 接线柱保留，并补充 `GND +5V IN` 丝印。
- 三路 GPIO 到栅极电阻、三路继电器线圈、U2 GND、K1 5V 等上一轮未连接项已收线。

剩余问题不是电气未连接，而是生产化整理：

- 自定义 `Codex:*` 占位 footprint 需要替换成真实 JLCEDA/KiCad 库封装。
- USB-C 需要按实际采购连接器核对外壳脚、定位孔、板边开口和装配方向。
- 当前 KiCad 预览和 Gerber/Drill 草包已经导出到 `hardware/kicad/out/`，仅用于检查层、孔、边框和布线，不建议直接下单。

## 不要重复的尝试

- 不要只在 PCB 端删除 `R8`。这样虽然能少一个 BOM 元件，但如果原理图没有同步删除或同步改 DNP，会产生 PCB/原理图网表不一致。
- 不要在当前 R1/5V/GPIO 密集区直接拉 `OPEN_COIL_LOW` 的 Q1-D1 横线；之前尝试会触发间距错误。
- 不要强行让 3V3 长线穿过 U2/R8/C2 密集区；如果要走这一路，先移动 R8 或 C2。

## 下一轮布线顺序

1. 先恢复 JLCEDA 客户端响应，确认当前文档是已保存的稳定基线，还是残留了未保存的 R8 实验状态。
2. 如果出现 `Netlist Error`，优先处理网表一致性：要么撤回 PCB 端 R8 删除，要么原理图和 PCB 同步删除/同步 DNP。
3. 将 KiCad 离线版新增的 USB-C、5V 输入丝印和收尾走线同步回 JLCEDA。
4. 替换占位 footprint：
   - 接线柱统一一个系列和间距。
   - USB-C 选低成本 16P/24P 常规母座，按供应链封装落地。
   - 继电器、AMS1117、MAX3485、AO3400A、二极管和 0603/0805 阻容全部换成可采购封装。
5. 生产化检查：
   - 先保证 clearance/physical 错误为 0。
   - 再确认 connection error 为 0。
   - 最后整理丝印、端子名称和装配可读性。

## 成本决策

- 保持 2 层板。
- 接线端子尽量统一间距和系列。
- 继电器 V1 只引出 `COM/NO`，现场明确需要 `NC` 再扩展。
- RS485 终端电阻、偏置电阻和保护器件默认作为可选/DNP 位。
- 如果要从 BOM 删除可选器件，必须同步更新原理图和 PCB，保证 DRC 仍有意义。

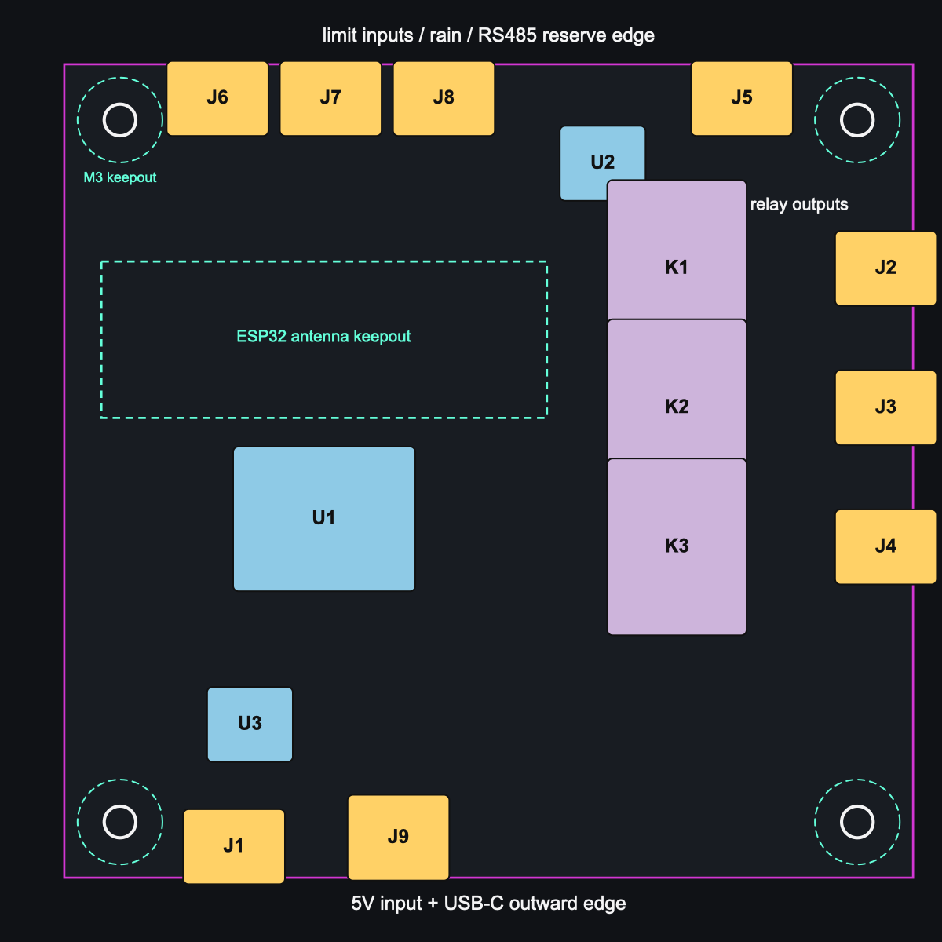
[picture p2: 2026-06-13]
hardware/jlceda/out/pcb3_outer_io_current_simplified.svg.png

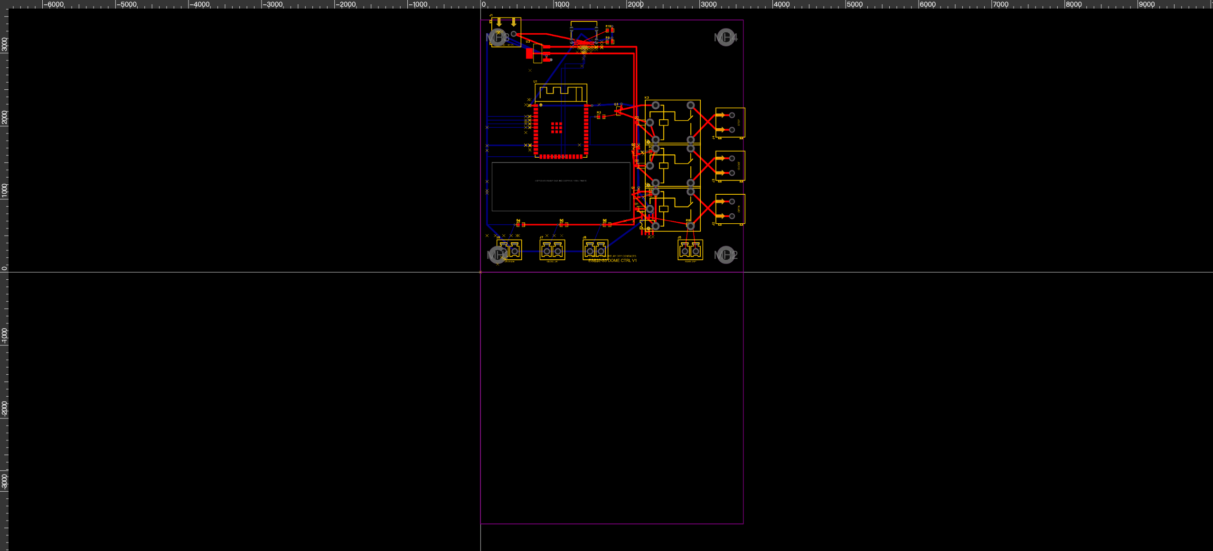
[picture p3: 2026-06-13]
hardware/jlceda/out/pcb3_outer_io_layout.png

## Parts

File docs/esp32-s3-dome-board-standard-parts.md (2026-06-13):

# ESP32-S3 Dome Board Standard Parts Assignment

Date: 2026-05-30

This file is the purchasing/assembly-facing standard parts allocation for JLCEDA `PCB3`.
Use it together with:

- `docs/esp32-s3-dome-board-standard-parts.csv`
- `docs/esp32-s3-dome-board-jlc-bom.csv`
- `docs/esp32-s3-dome-board-jlc-source-check.md`
- `docs/esp32-s3-dome-board-jlceda-parts-manifest.csv`
- `scripts/jlceda_verify_lcsc_parts.mjs`

## Standardization Result

- JLCEDA component refs checked by script: `30`.
- Default fitted component refs: `27`.
- Default DNP component refs: `3` (`U2`, `R8`, `J5` for RS485 reserve).
- Mechanical-only refs: `MH1`..`MH4`, not included in assembly BOM.
- Resistor package policy: keep all resistors as 0603 to reduce assembly variety.
- Connector policy: 5.08mm terminals for external 5V and relay dry contacts; 3.81mm terminals for low-voltage inputs and RS485 reserve.

## Policy

- Prefer JLCPCB Basic SMT parts for resistors, MOSFETs, diodes, and regulators.
- Accept Extended parts when the package defines the board interface or module choice: ESP32-S3 module, relay, terminals, and USB-C.
- Keep RS485 unassembled by default for V1 to reduce assembly cost and avoid committing to a field bus before it is needed.
- Keep all external wiring on screw terminals or USB-C; do not replace field terminals with pin headers for the production candidate.
- Re-check live stock, price, and JLCPCB assembly availability immediately before ordering.
- Treat this document and `docs/esp32-s3-dome-board-standard-parts.csv` as the standard-parts authority; treat JLCEDA-exported BOM/CPL as the final order files after netlist sync.

## FIT Standard Parts

| Ref | Qty | Standard Part | LCSC | Class | Package / Footprint | Reason |
| --- | ---: | --- | --- | --- | --- | --- |
| U1 | 1 | ESP32-S3-WROOM-1-N8R8 | C2913201 | Extended | WIRELM-SMD_ESP32-S3-WROOM-1 | Main MCU/Wi-Fi module; integrated antenna; official footprint required. |
| U3 | 1 | AMS1117-3.3 | C6186 | Basic | SOT-223-3 | Low-cost 5V to 3V3 regulator for V1. |
| K1 K2 K3 | 3 | SRD-05VDC-SL-C | C35449 | Extended | RELAY-TH_SRD-XXVDC-XL-C | 5V relay dry-contact outputs for OPEN/CLOSE/STOP. |
| Q1 Q2 Q3 | 3 | AO3400A | C20917 | Basic | SOT-23 | Low-side relay coil drivers. |
| D1 D2 D3 | 3 | 1N4148W | C81598 | Basic | SOD-123F | Flyback diodes for relay coils. |
| R1 R2 R3 | 3 | 100R 0603 | C22775 | Basic | R0603 | MOSFET gate resistors. |
| R4 R5 R6 | 3 | 10k 0603 | C25804 | Basic | R0603 | Input pullups for limit/rain inputs. |
| R9 R10 | 2 | 5.1k 0603 | C23186 | Basic | R0603 | USB-C CC pulldowns. |
| J1 | 1 | WJ500V-5.08-2P | C8465 | Extended | 5.08mm 2P terminal | External GND/+5V input. |
| J2 J3 J4 | 3 | WJ500V-5.08-2P | C8465 | Extended | 5.08mm 2P terminal | Relay dry-contact output terminals. |
| J6 J7 J8 | 3 | KF128-3.81-2P | C9900005589 | Extended | 3.81mm 2P terminal | OPEN limit, CLOSE limit, and RAIN inputs. |
| J9 | 1 | TYPE-C-31-M-12 | C165948 | Extended | USB-C_SMD-TYPE-C-31-M-12_1 | Native ESP32-S3 USB download/debug port. |

## Default DNP / Reserved Parts

| Ref | Qty | Standard Part | LCSC | Class | Package / Footprint | Default |
| --- | ---: | --- | --- | --- | --- | --- |
| U2 | 1 | SP3485EN-L/TR | C8963 | Basic | SOIC-8 | DNP; populate only when RS485 is needed. |
| R8 | 1 | 120R 0603 | C22787 | Basic | R0603 | DNP; RS485 terminal resistor. |
| J5 | 1 | KF128-3.81-2P | C9900005589 | Extended | 3.81mm 2P terminal | DNP; RS485 A/B reserve terminal. |

## Mechanical / Non-BOM

| Ref | Qty | Standard | Notes |
| --- | ---: | --- | --- |
| MH1 MH2 MH3 MH4 | 4 | M3 NPTH, about 3.4mm drill | Board fabrication holes only; keep screw-head/component clearance around each hole. |

## Allowed Substitutions

Use substitutions only if the selected standard part is unavailable or the exact ordered part cannot be assembled by JLCPCB.

| Function | Preferred | Allowed Substitute Rule |
| --- | --- | --- |
| 0603 resistors | Listed C22775/C25804/C22787/C23186 | Same value, 0603, 1% or 5%, JLCPCB Basic preferred, same footprint `R0603`. |
| Relay driver MOSFET | AO3400A C20917 | Logic-level N-MOSFET, SOT-23, Vds >= 30V, low Rds(on) at 2.5V gate drive, same pinout. |
| Flyback diode | 1N4148W C81598 | SOD-123/SOD-123F switching diode with matching footprint and current margin for relay coil. |
| USB-C | TYPE-C-31-M-12 C165948 | Only substitute with verified footprint-compatible USB-C receptacle; check locator holes and shell pads before order. |
| Relay | SRD-05VDC-SL-C C35449 | 5V coil, matching SRD footprint/pinout, contact rating suitable for the external controller input; re-check coil current. |
| Terminal blocks | C8465 / C9900005589 | Same pitch and footprint family; do not mix 3.81mm and 5.08mm footprints without changing PCB. |

## Final Order Gate

Before generating the final JLCPCB order package:

- Run `node scripts/jlceda_verify_lcsc_parts.mjs`.
- Confirm `J5`, `R8`, and `U2` remain excluded from BOM unless RS485 is intentionally included.
- Re-check live JLCPCB stock/assembly status for all Extended parts.
- Synchronize/import the schematic netlist and clear the remaining `Netlist Error / Import Changes` item in JLCEDA UI DRC.
- Re-run physical checks:
  - `node scripts/jlceda_verify_mounting_clearance.mjs`
  - `node scripts/jlceda_check_clearance.mjs`
  - `node scripts/jlceda_find_open_nets_layered.mjs`
  - `node scripts/jlceda_verify_antenna_keepout.mjs`

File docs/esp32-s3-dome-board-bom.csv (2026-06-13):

Designator | Qty | Value | Package/Footprint Plan | LCSC Part | Fit | Cost Note
U1 | 1 | ESP32-S3-WROOM-1-N8R8 | Castellated module | C2913201 | FIT | Use module to avoid RF layout and certification risk
U3 | 1 | AMS1117-3.3 | SOT-223 | C6186 | FIT | Cheap for first 5V input version; consider buck only if heat is high
U2 | 1 | SP3485EN-L/TR | SOIC-8 | C8963 | DNP by default | Reserve RS485; do not fit if switch-output mode is enough
K1 K2 K3 | 3 | SRD-05VDC-SL-C | Songle SRD relay footprint | C35449 | FIT | Lowest-risk field wiring; only COM/NO routed to reduce terminal cost
Q1 Q2 Q3 | 3 | AO3400A | SOT-23 | C20917 | FIT | Low-cost relay coil drivers
D1 D2 D3 | 3 | 1N4148W | SOD-123 | C81598 | FIT | Relay flyback diodes
R1 R2 R3 | 3 | 100R | 0603 | C22775 | FIT | MOSFET gate resistors; JLC Basic part
R4 R5 R6 | 3 | 10k | 0603 | C25804 | FIT | Input pullups; JLC Basic part
R8 | 1 | 120R | 0603 | C22787 | DNP by default | RS485 terminal resistor; JLC Basic part
R9 R10 | 2 | 5.1k | 0603 | C23186 | FIT | USB-C CC pulldowns; JLC Basic part
J1 | 1 | 2P 5.08mm terminal | 5.08mm | C8465 | FIT | External GND/+5V input; cheaper than adding onboard 12/24V buck in V1
J2 J3 J4 | 3 | 2P 5.08mm terminal | 5.08mm | C8465 | FIT | Relay dry-contact outputs OPEN/CLOSE/STOP
J5 | 1 | 2P 3.81mm terminal | 3.81mm | C9900005589 | DNP by default | RS485 A/B reserved
J6 J7 J8 | 3 | 2P 3.81mm terminal | 3.81mm | C9900005589 | FIT | OPEN limit/CLOSE limit/RAIN input
J9 | 1 | USB-C receptacle | HRO TYPE-C-31-M-12 | C165948 | FIT | Native ESP32-S3 USB; no USB-UART chip needed
MH1 MH2 MH3 MH4 | 4 | M3 NPTH | 3.4mm drill | N/A | FIT | No plating required; low-cost mechanical mounting

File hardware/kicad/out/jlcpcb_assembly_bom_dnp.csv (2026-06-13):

Comment | Designator | Footprint | LCSC Part # | JLCPCB Class
SP3485EN-L/TR | U2 | Package_SO:SOIC-8_3.9x4.9mm_P1.27mm | C8963 | Basic
120R | R8 | Resistor_SMD:R_0603_1608Metric | C22787 | Basic
3.81mm 2P terminal | J5 | EasyEDA CONN-TH_P3.81_KF128L-3.81-2P-1 | C9900005589 | Extended

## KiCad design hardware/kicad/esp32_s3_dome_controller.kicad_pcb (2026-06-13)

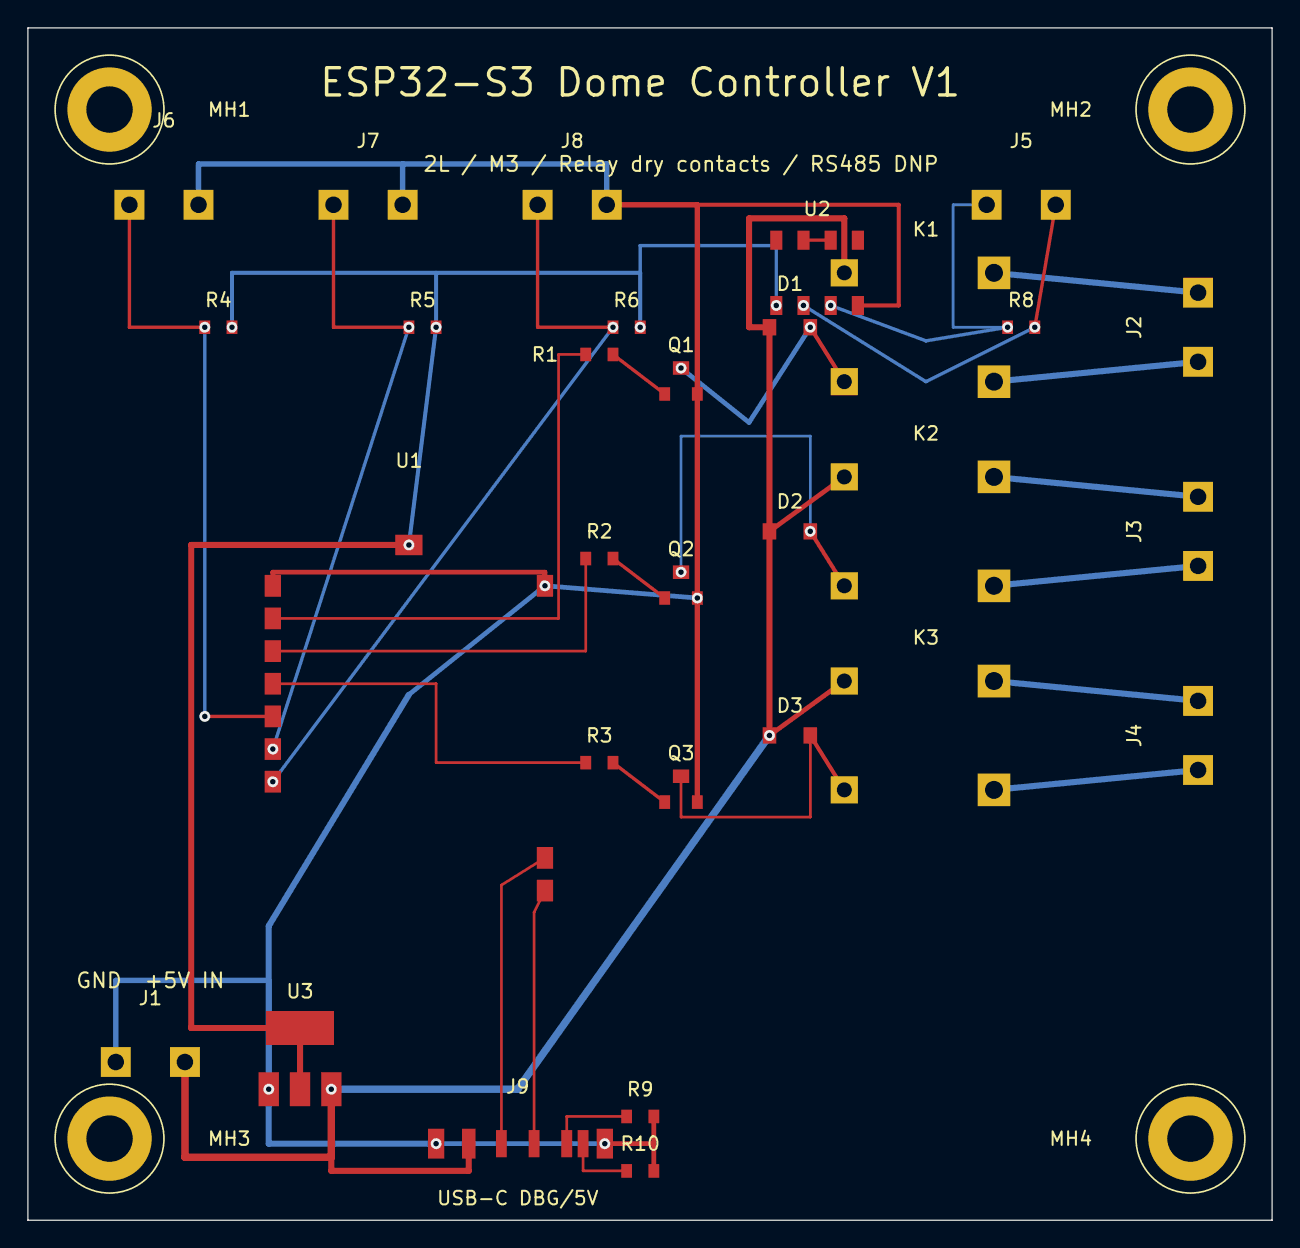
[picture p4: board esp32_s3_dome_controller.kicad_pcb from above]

Board: 2 copper layers, 91.4 x 87.6 mm, 34 parts (0 on the bottom side), 28 nets.

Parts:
D1: 1N4148/SS14; D1
D2: 1N4148/SS14; D2
D3: 1N4148/SS14; D3
J1: 5V IN; J1
J2: OPEN OUT; J2
J3: CLOSE OUT; J3
J4: STOP OUT; J4
J5: RS485; J5
J6: OPEN LIMIT; J6
J7: CLOSE LIMIT; J7
J8: RAIN; J8
J9: USB-C DEVICE; J9
K1: SRD-05VDC-SL-C; K1
K2: SRD-05VDC-SL-C; K2
K3: SRD-05VDC-SL-C; K3
MH1: M3 NPTH; MH1
MH2: M3 NPTH; MH2
MH3: M3 NPTH; MH3
MH4: M3 NPTH; MH4
Q1: AO3400A; Q1
Q2: AO3400A; Q2
Q3: AO3400A; Q3
R1: 100R; R1
R2: 100R; R2
R3: 100R; R3
R4: 10k pullup; R4
R5: 10k pullup; R5
R6: 10k pullup; R6
R8: 120R DNP; R8
R9: 5.1k; R9
R10: 5.1k; R10
U1: ESP32-S3-WROOM-1; U1
U2: MAX3485; U2
U3: AMS1117-3.3; U3

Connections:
3V3: R4.2, R5.2, R6.2, U1.3V3, U2.8, U3.2, U3.4
5V: D1.1, D2.1, D3.1, J1.2, J9.VBUS, K1.COIL+, K2.COIL+, K3.COIL+, U3.3
CLOSE_COIL_LOW: D2.2, K2.COIL-, Q2.3
CLOSE_COM: J3.2, K2.COM
CLOSE_GATE: Q2.1, R2.2
CLOSE_GPIO5: R2.1, U1.5
CLOSE_LIMIT_GPIO8: J7.1, R5.1, U1.12
CLOSE_NO: J3.1, K2.NO
GND: J1.1, J6.2, J7.2, J8.2, J9.GND1, J9.GND2, Q1.2, Q2.2, Q3.2, R9.2, R10.2, U1.1, U1.40, U2.5, U3.1
OPEN_COIL_LOW: D1.2, K1.COIL-, Q1.3
OPEN_COM: J2.2, K1.COM
OPEN_GATE: Q1.1, R1.2
OPEN_GPIO4: R1.1, U1.4
OPEN_LIMIT_GPIO7: J6.1, R4.1, U1.7
OPEN_NO: J2.1, K1.NO
RAIN_GPIO9: J8.1, R6.1, U1.17
RS485_A: J5.1, R8.1, U2.6
RS485_B: J5.2, R8.2, U2.7
RS485_RE_DE: U2.2, U2.3
STOP_COIL_LOW: D3.2, K3.COIL-, Q3.3
STOP_COM: J4.2, K3.COM
STOP_GATE: Q3.1, R3.2
STOP_GPIO6: R3.1, U1.6
STOP_NO: J4.1, K3.NO
USB_CC1: J9.CC1, R9.1
USB_CC2: J9.CC2, R10.1
USB_D+: J9.D+, U1.20
USB_D-: J9.D-, U1.19

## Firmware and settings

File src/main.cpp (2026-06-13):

#define DOME

#ifdef DOME
/*
Usually I expect to have a gate board, but in the last time I found some guys that handle the motor with two realys, open and close
Only in this case comment the #define GATE_BOARD
#start pin will be open command
#halt pin will be close command
*/
#define GATE_BOARD
#endif

#include <WiFi.h>
#include "AsyncJson.h"
#include "AsyncUDP.h"
#include "HTTPClient.h"
#include <ESPAsyncWebServer.h>
#include <ESPAsyncWiFiManager.h>
#include <stdint.h>
#include "SPIFFS.h"
#include "board_pins.h"
#include "Dome/domeVariable.h"
#include "header.h"
#include <ElegantOTA.h>

AsyncWebServer server(80);
AsyncWebServer Alpserver(4567);

#include "Alpaca/AlpacaManageFunction.h"
#ifdef DOME
#include "Dome/dome.h"
#include "Dome/serialControl.h"
#endif

#include "browserServer.h"
#include "configuration.h"

#include "loop.h"
DNSServer dns;
AsyncUDP udp;

void ServerNotFound(AsyncWebServerRequest *request) {
  request->send(404, "text/plain", "Not found");
  Serial.println("404");
  Serial.println(request->url());
}

void setup()
{
  Serial.begin(115200);
  AlpacaData.serverTransactionID = 0;
/* reading configuration from file */
  if (!SPIFFS.begin()) { Serial.println("An Error has occurred while mounting SPIFFS"); return; }

  #ifdef DOME
  initDomeConfig();
  domeSerialSetup();
  Serial.println("dome init done");
  #endif

  Serial.println("Listening for discovery requests...");
  AsyncWiFiManager wifiManager(&server,&dns);
  wifiManager.autoConnect();
  Serial.print("Connect with IP Address: ");
  Serial.println(WiFi.localIP());


  if (udp.listen(32227))
  {
    Serial.println("Listening for discovery requests...");
    udp.onPacket([](AsyncUDPPacket packet) {
      if (packet.length() < 16)
      {
        return;
      }
      //Compare packet to Alpaca Discovery string
      if (strncmp("alpacadiscovery1", (char *)packet.data(), 16) != 0)
      {
        return;
      }
      packet.printf("{\"alpacaport\": 4567}");
    });
  }

  Alpserver.onNotFound(notFound);
  /*** MANAGE AREA ***/

  AlpacaManager();
  #ifdef DOME
  domeServer();
  #endif
  
  browserServer();

  Alpserver.begin();
  ElegantOTA.begin(&server);
  server.begin();
  Dome.lastCommunicationMillis = millis();
  Serial.println("setup done");
}

void loop(){
  main_loop();
}

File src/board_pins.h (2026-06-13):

#ifndef BOARD_PINS_H
#define BOARD_PINS_H

// ESP32-S3 dome controller board pin map.
// Relay outputs drive isolated trigger inputs for open, close, and stop.
#define PIN_OPEN_START 4
#define PIN_CLOSE_START 5
#define PIN_HALT_START 6

// Limit switch inputs. Wire external pull-ups/pull-downs to match domeInputState().
#define PIN_OPEN 7
#define PIN_CLOSE 8

// Reserved rain sensor header. The input is initialized but not used for
// automatic closing until the hardware polarity is known.
#define PIN_RAIN_SENSOR 9

#endif

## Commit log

2026-05-21 Focus firmware on dome serial control
    Trim the firmware and UI to the sliding dome control surface, then add a small serial protocol that reuses the existing dome state machine for ASCOM driver work.
    Constraint: Target board only needs dome roof control and an ASCOM 6.6+ serial-driver path.
    Rejected: Keeping dormant Switch/CoverCalibrator modules | They kept stale discovery, UI, and configuration surfaces alive.
    Confidence: high
    Scope-risk: moderate
    Directive: Keep serial commands as thin adapters over Dome.ShutterCommand and Dome.ShutterState; do not duplicate motor-control logic in driver-specific code.
    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
    [ccalibconfig.txt, configuration.h, switchconfig.txt]
2026-05-21 Localize dome web UI for Chinese operators
    Translate remaining English and Italian interface strings in the dome pages, then regenerate the compressed SPIFFS web assets.
    Constraint: User only asked for html_pages translation; firmware behavior stays unchanged.
    Rejected: Reworking layout or adding i18n framework | broader than a text localization pass.
    Scope-risk: narrow
    Directive: Keep future UI copy in Chinese unless adding an explicit language switch.
    Tested: npm run build; checked generated gzip pages for old UI terms.
    Not-tested: Browser rendering on physical ESP32.
    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
2026-06-13 Add ESP32-S3 dome board hardware package
    [domeconfig.txt, esp32-s3-dome-board-bom.csv, esp32-s3-dome-board-footprint-map.csv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]
